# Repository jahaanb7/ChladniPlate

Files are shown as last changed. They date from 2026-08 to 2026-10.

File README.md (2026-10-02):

# Chladni Plate — Turning sound into visual patterns

A Chladni Plate is a demonstration device that shows stunning visual patterns made from vibrating sand on a plate. Using a mechanical wave driver, we can convert digital audio into mechanical vibrations, which can vibrate the plate at certain frequencies to form specific standing wave patterns. These standing waves have regions of no oscillation called "nodal lines," and regions of oscillations are called "antinodes."

## System Overview:

The system uses a subwoofer to act as a DIY mechanical driver by connecting screws to its body in order to carry the vibrations. The subwoofer is connected to an amplifier which amplifies the sound to produce greater vibrations that can move the plate better. The amplifier is connected to a laptop or you can connect it to a microcontroller and upload a software to generate and control frequencies. 

Flowchart Diagram:

Signal Source (Laptop/Microcontroller) --> Amplifier (eg., TPA3116) --> Subwoofer (6.5 inches for me) --> (vibrates) metal/aluminum sheet

## How to Assemble:

### Tools Needed:
These tools are needed to assembly the Chladni plate, this does not include the BOM

- soldering iron
- audio cable/usb-a cable
- drill/screw driver
- 3d printer and filament

1) Using a 3D printer, print out the 'enclosure' step file. I recommend these settings: 25% - 30% infill, Filament: PLA or ABS
2) Heat up your soldering iron to a fairly high temperature (200-300 celsius— not very hot) and place the appropriate size heat-set inserts (the holes where the subwoofer goes are M3 heat-set inserts, while the other heat-set inserts for the cap of the amplifier board are M5) and press the tip of the soldering iron onto the heat-set inserts until they melt the plastic around and go into their respective holes.
3) Repeat for every place for which there is a hole in the enclosure, there should only be 8
4) Drill or make a hole in the center of the subwoofer and insert the threaded rod there, insert the other thread rods into each hole in the enclosure. Then for the outer threaded rods insert a M3 nut from the top and let it go down 1 cm.
5) Then carefully place the acrylic sheet through all the holes and make sure the the nuts can support the acrylic sheet.
6) Now place a nut on the center thread rod (the taller one) and spin it until it's down a centimeter as well. Then place the aluminum sheet through the hole and put another M3 nut on top with a washer attached.
7) Place the amplifier board into the dedicated region on the side of the enclosure.
8) Then connect the subwoofer wires through the holes in the enclosure and screw them onto the board. Also connect the USB-A / audio jack wire from your audio source (laptop) through the hole behind and connect that to the amplifier. You also have to connect a DC power supply (9V-24V) to the amplifier board.
9) Then place the cap on the top and screw in M3 size counter head screws until the cap is secured. And you're done!

## Bill of Materials

<details>
<summary>Expand BOM</summary>

| Item | Specification | Qty | Unit Price (CAD) | Total (CAD) | Source |
|---|---|---:|---:|---:|---|
| Subwoofer | 6.5-inch coaxial car speaker, 100W/160W | 1 | $20.79 | $20.79 | AliExpress — Woman Center Store |
| M3 Washers | 304 stainless steel flat washer, 50pcs pack | 1 | $1.42 | $1.42 | AliExpress — JiYu320 Store |
| Aluminum Plate | 200mm × 200mm, 1mm thick | 1 | $11.58 | $11.58 | AliExpress — MetalHome Wholesale Store |
| Brass Insert Nuts & Screws | M3A assortment kit, 420pcs | 1 | $14.64 | $14.64 | AliExpress — YMAX A Salted Fish Store |
| TPA3116D2 Amplifier Board | XY-1001W, 100W mono, potentiometer all-in-one | 1 | $16.28 | $16.28 | AliExpress — Tech Hub 103 Store |
| Acrylic Sheet | 150mm × 150mm, 1mm thick | 1 | $1.63 | $1.63 | AliExpress — Disen Tools Store |
| M3 Threaded Rod | DIN975, 304 stainless steel, M3 × 90mm, 5pcs/pack | 1 | $1.40 | $1.40 | AliExpress |
| M3 Lock Nuts | 304 stainless steel, black hex, nylon insert self-locking nut | 1 | $1.40 | $1.40 | AliExpress |

### Total Cost 

| | Cost (CAD) |
|---|---:|
| **Items Subtotal** | **$69.46** |
| Shipping | $13.63 |
| **Estimated Total** | **$83.09** |

</details>

## Wiring Diagram:

### Screenshot 2026-08-19 at 11 29 45 PM

### Screenshot 2026-10-02 at 1 37 36 AM

## CAD Images

Screenshot 2026-08-20 at 12 03 26 AM

Screenshot 2026-08-20 at 12 04 33 AM

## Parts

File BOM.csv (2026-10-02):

Item | Specification | Qty | Unit Price (CAD) | Total (CAD) | Source | Link
M3 Washers | 304 stainless steel flat washer, 50pcs pack | 1 | 1.42 | 1.42 | AliExpress - JiYu320 Store | https://www.aliexpress.com/item/1005004133884905.html
Aluminum Plate | 200mm x 200mm, 1mm thick | 1 | 11.58 | 11.58 | AliExpress - MetalHome Wholesale Store | https://www.aliexpress.com/item/1005010781576808.html
Brass Insert Nuts & Screws | M3A assortment kit, 420pcs | 1 | 14.64 | 14.64 | AliExpress - YMAX A Salted Fish Store | https://www.aliexpress.com/item/1005005467831636.html
TPA3116D2 Amplifier Board | XY-1001W, 100W mono, potentiometer all-in-one | 1 | 16.28 | 16.28 | AliExpress - Tech Hub 103 Store | https://www.aliexpress.com/item/1005009268771211.html
Acrylic Sheet | 150mm x 150mm, 1mm thick | 1 | 1.63 | 1.63 | AliExpress - Disen Tools Store | https://www.aliexpress.com/item/1005009867398893.html
M3 Threaded Rod | DIN975, 304 stainless steel, M3 x 90mm, 5pcs/pack | 1 | 1.40 | 1.40 | AliExpress | https://www.aliexpress.com/item/1005003590615453.html
M3 Lock Nuts | M3 304 stainless steel black hex nylon insert self-locking nut | 1 | 1.40 | 1.40 | AliExpress | https://www.aliexpress.com/item/1005009539464446.html
 |  | Items Subtotal |  | 48.35
 |  | Shipping |  | 13.63
 |  | Estimated Total |  | 61.98

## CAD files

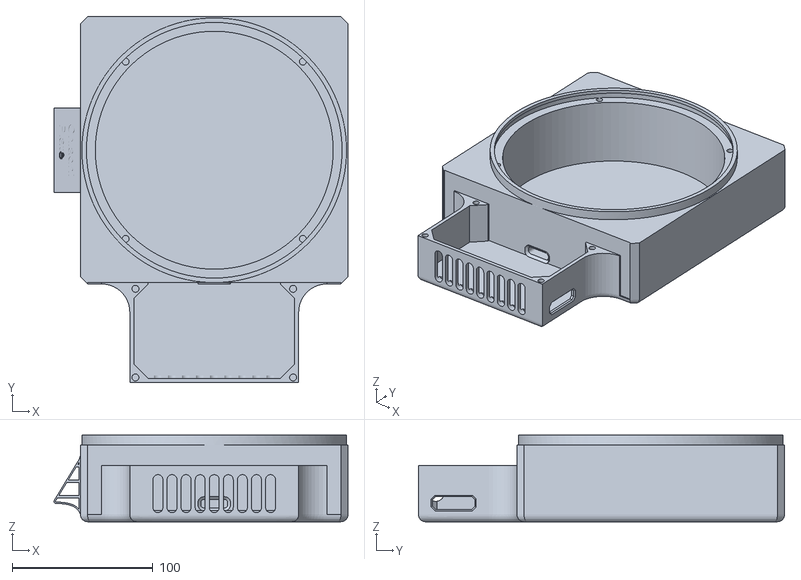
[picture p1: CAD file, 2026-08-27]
production/enclosure_V2.stl
208.8 x 260.0 x 61.5

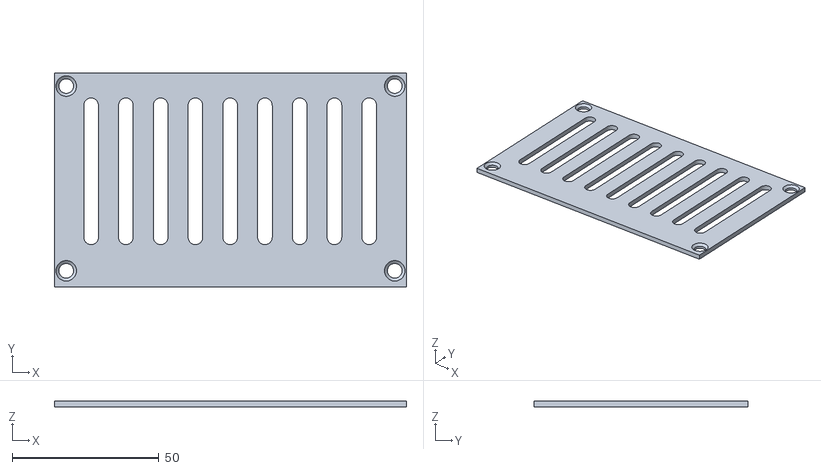
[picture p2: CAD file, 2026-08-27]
production/enclosure_cap.stl
120.0 x 72.9 x 2.00

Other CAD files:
production/CAD/ChladniPlate_Master.step

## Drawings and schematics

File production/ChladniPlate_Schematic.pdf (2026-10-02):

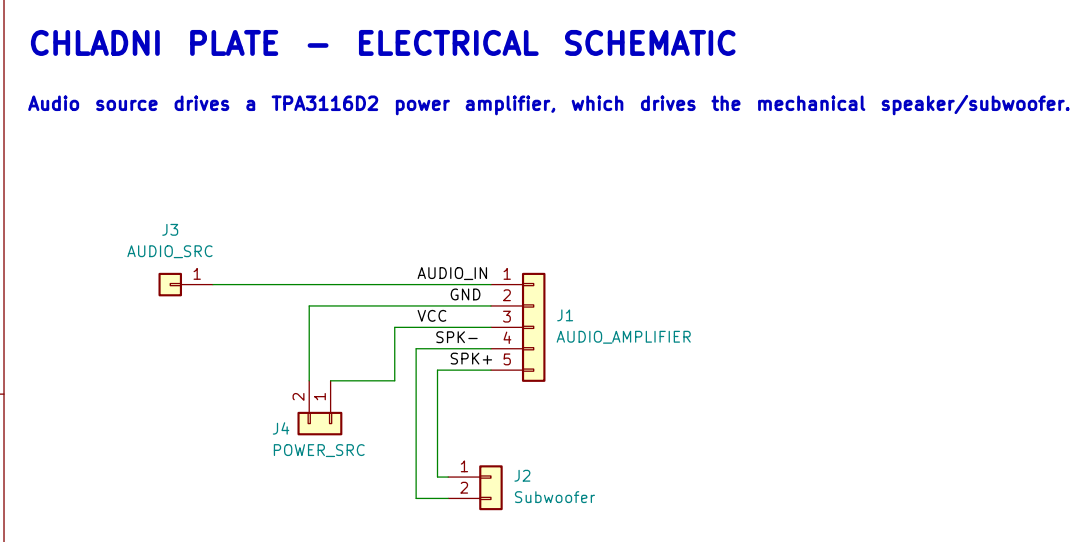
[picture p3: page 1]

SPK+ CHLADNI PLATE - ELECTRICAL SCHEMATIC

Audio source drives a TPA3116D2 power amplifier, which drives the mechanical speaker/subwoofer.

Size: A4 | Rev:
KiCad E.D.A. 10.0.0 | Id: 1/1

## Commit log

2026-08-08 Add images to README for Chladni plate project
    Added images to the README to showcase Chladni plate results.
2026-08-08 Revise README for clarity and detail
    Updated the README to provide a clearer overview of the Chladni Plate project, including details on how it works, wiring instructions, and important notes for users.
2026-08-08 Remove 'markdown' from BOM/Bill
    Removed 'markdown' from the Bill of Materials file.
2026-08-08 Revise assembly instructions and add detailed steps
    Updated assembly instructions and added detailed steps for 3D printing, installing components, and wiring.
2026-08-20 Revise README for Chladni Plate project
    Updated the README to enhance clarity and detail about the Chladni Plate project, including assembly instructions and system overview.
2026-08-20 Update README with assembly instructions and tools
    Added tools needed and assembly instructions for the Chladni plate, including detailed steps for construction and wiring.
2026-08-20 Rename bom (2).csv to BOM.csv
    [BOM.csv]
2026-08-27 Add Bill of Materials to README
    Added a Bill of Materials section with item specifications and costs.
2026-10-02 Add new wiring diagram image to README
    Added a new wiring diagram image to the README.
2026-10-02 Add item links and update header in BOM.csv
    Updated BOM.csv to include links for each item and corrected the header.
    [BOM.csv]
2026-10-02 Update BOM.csv to add header and correct links
    [BOM.csv]
2026-10-02 Update item prices and links in BOM.csv
    Updated BOM.csv to reflect new item prices and links.
    [BOM.csv]
